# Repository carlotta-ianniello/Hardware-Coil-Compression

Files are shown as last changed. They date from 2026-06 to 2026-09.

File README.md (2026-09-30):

# Hardware Coil Compression

This repository includes the PCB design for a 4x4 mixing matrix that can be used to perform MRI hardware compression at 7T. 

<p align="center">
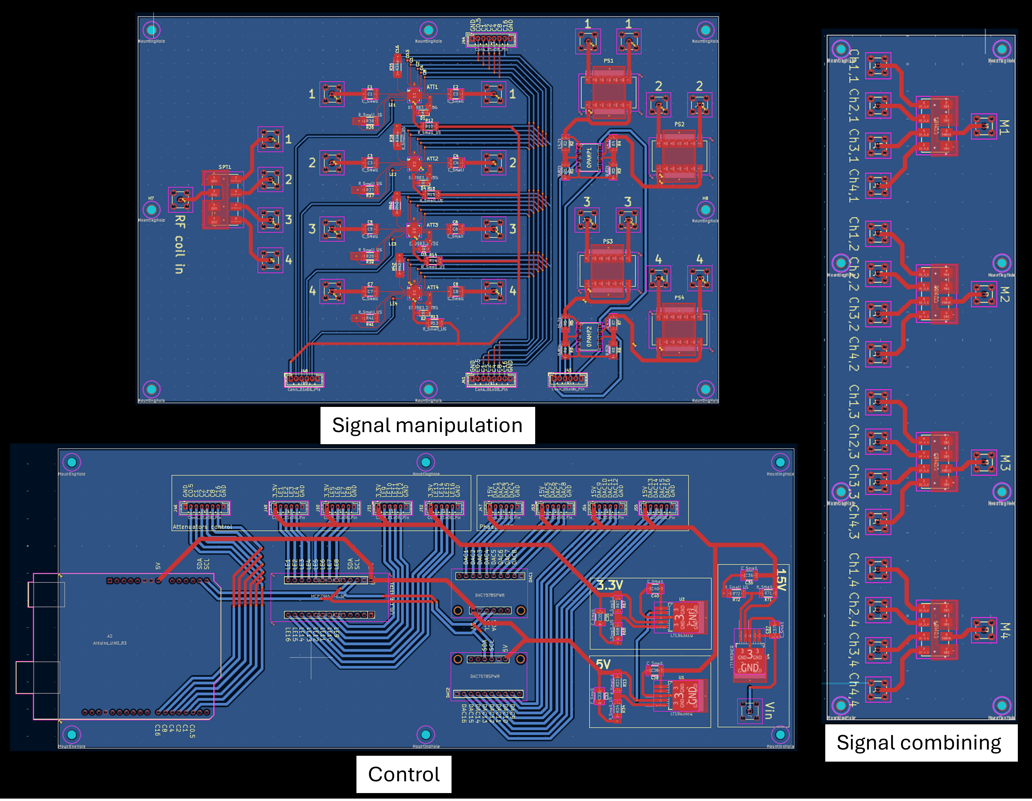
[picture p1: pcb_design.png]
  
</p>

# PCA Compression
The MATLAB script pca_compression_pipeline_ROI.mat calculates the PCA-based weights for coil compression. 

* Load signal and noise data
* Compute noise covariance Psi (for pre-whitening)
* If n_coils=8: evaluate all candidate 4-channel subsets and select the one whose compression matrix phases best fit the hardware phase range, with priority on modes 1 & 2
* Build ROI mask (SNR threshold, radial crop, or both)
* Compute pre-whitened PCA via SVD
* Optimise per-mode global phase rotation into hardware range
* Compute SNR retention maps for 4/3/2/1 virtual modes
* Save compression matrix A for calculate_settings_complex.m

When an ROI is selected or loaded, PCA is only performed in the ROI.

# Settings calculation
The MATLAB script calculate_settings_complex.mat generates optimized hardware settings for a 4×4 RF compression matrix using measured calibration data. It supports loading a target compression matrix, generating random test matrices, or manually defining custom amplitude and phase targets.

The script:

* Loads and normalizes calibration measurements for attenuation and phase
* Interpolates calibration data to a uniform resolution
* Matches target amplitude/phase values to the closest hardware configuration
* Computes attenuator settings, phase shifter voltages, and binary control values for each channel
* Exports the resulting configuration as a `.h` header file for direct integration into the Arduino IDE

This tool is designed for automated calibration and control of modular 4×4 RF matrix hardware systems.

# IDE code
The code to run the compression matrix is included in IDE/4x4_matrix_settings. 

The user will have to insert the correct I2C addresses for DACX578 and MCP23X17:

```cpp
// DAC and I/O Port Expander Addresses
#define DAC1_ADDR 0x4C   // First DAC (0-7 channels)
#define DAC2_ADDR 0x4A   // Second DAC (8-14 channels)
#define IOEXP_ADDR 0x20  // I/O Port Expander
```

Furthermore, in setOutputVoltage supply voltage at the input of the Op Amps needs to be defined. The Op Amp gain is set to 3 but this can also be adjusted based on the resistor values one uses.

```cpp
void setOutputVoltage(int row, int col, float voltage) {
  int index = row * ncol + col; // Flatten 2D to 1D index
  const float ampGain = 3;
  float dacOutputVoltage = voltage / ampGain;
  const float Vcc = 4.07;  // Vcc of Op Amp
  uint16_t dacValue = (uint16_t)round((dacOutputVoltage / Vcc) * 4095);
 ...
```

An example of settings is included in setting1.h.

# Bill of Materials
The complete bill of materials for this project can be found in BOM.xlsx, comprehensive of links to vendors and cost. 

# Reference 
If you use this work, please cite it as follows:

```bibtex
@inproceedings{Ianniello2026,
  author    = {Ianniello, C. and Brown, R.},
  title     = {A flexible hardware-based fully programmable mode-mixing matrix for channel compression applications},
  booktitle = {2026 ISMRM \& ISMRT Annual Meeting \& Exhibition},
  address   = {Cape Town, South Africa},
  year      = {2026}
}
```

C. Ianniello and R. Brown, "A flexible hardware-based fully programmable mode-mixing matrix for channel compression applications," in 2026 ISMRM & ISMRT Annual Meeting & Exhibition, Cape Town, South Africa, 2026.

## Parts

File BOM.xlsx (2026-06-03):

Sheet: first draft
Part number | Description | Vendor | Quantity | Unit Price | Total Price = | Link
DAT-31R5A-PP+ | Step attenuator | Mini-Circuits | 6 | $6.11 | $36.66 | https://www.minicircuits.com/WebStore/dashboard.html?model=DAT-31R5A-PP%2B
JSPHS-42+ | Phase Shifter | Mini-Circuits | 6 | $44.21 | $265.26 | https://www.minicircuits.com/WebStore/dashboard.html?model=JSPHS-42%2B
SCP-4-1W+ | 4 ways splitter | Mini-Circuits | 4 | $34.09 | $136.36 | https://www.minicircuits.com/WebStore/dashboard.html?model=SCP-4-1W%2B
LM358NNS/NOPB-ND | IC OPAMP GP 2 CIRCUIT 8DIP | DigiKey | 10 | $0.55 | $5.50 | https://www.digikey.com/en/products/detail/texas-instruments/LM358N-NOPB/6264?gad_source=1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
AE9986-ND | CONN IC DIP SOCKET 8POS TIN | DigiKey | 10 | $0.13 | $1.34 | https://www.digikey.com/en/products/detail/assmann-wsw-components/A-08-LC-TT/821740
1124-1424-ND | CONN NIMCAMAC RCPT STR 50OHM PCB | DigiKey | 4 | $21.97 | $87.88 | https://www.digikey.com/en/products/detail/lemo/EPB-00-250-NTN/3597321
SAM8944-ND | CONN MCX JACK STR 50 OHM PCB | DigiKey | 30 | $2.82 | $84.46 | https://www.digikey.com/en/products/detail/samtec-inc/MCX-J-P-H-ST-TH1/2685236
LT1963AEQ#TRPBFCT-ND | IC REG LIN POS ADJ 1.5A DDPAK-5 | DigiKey | 4 | $8.79 | $35.16 | https://www.digikey.com/en/products/detail/analog-devices-inc/LT1963AEQ-PBF/807749?gad_source=1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
CRCW201010K0FKEF | RES SMD 10K OHM 1% 3/4W 2010 | DigiKey | 50 | $0.12 | $5.85 | https://www.digikey.com/en/products/detail/vishay-dale/CRCW201010K0FKEF/1174057
CRCW201015K0FKEF | RES SMD 15K OHM 1% 3/4W 2010 | DigiKey | 50 | $0.12 | $5.85 | https://www.digikey.com/en/products/detail/vishay-dale/CRCW201015K0FKEF/1198590
VJ0603Y102JXAAC | CAP CER 1000PF 50V X7R 0603 | DigiKey | 50 | $0.21 | $10.55 | https://www.digikey.com/en/products/detail/vishay-vitramon/VJ0603Y102JXAAC/8305189
315-NC191-ND | SMOOTH FLOW TACK FLUX NO-CLEAN I | DigiKey | 1 | $9.95 | $9.95 | https://www.digikey.com/en/products/detail/chip-quik-inc/NC191/11480391
4902P-25G | LEAD FREE LOW TEMPERATURE SOLDER | DigiKey | 1 | $34.67 | $34.67 | https://www.digikey.com/en/products/detail/mg-chemicals/4902P-25G/7496977
 |  |  |  | TOTAL | $719.49

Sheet: modular board
Part number | Description | Vendor | Qty | Unit Price | Total Price | Link
Arduino UNO R3 | Arduino microcontroler | Arduino | 1 | $27.60 | $27.60 | https://store-usa.arduino.cc/products/arduino-uno-rev3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
DAT-31R5A-PP+ | Step attenuator | Mini-Circuits | 16 | $6.35 | $101.60 | https://www.minicircuits.com/WebStore/dashboard.html?model=DAT-31R5A-PP%2B
JSPHS-42+ | Phase Shifter | Mini-Circuits | 16 | $44.21 | $707.36 | https://www.minicircuits.com/WebStore/dashboard.html?model=JSPHS-42%2B
SCP-4-1W+ | 4 ways splitter/combiner | Mini-Circuits | 8 | $34.09 | $272.72 | https://www.minicircuits.com/WebStore/dashboard.html?model=SCP-4-1W%2B
MCP23017 | 16-port GPIO | Adafruit | 1 | $5.95 | $5.95 | https://www.adafruit.com/product/5346
DAC7578 | 8-port DAC 12-bit | Adafruit | 2 | $24.95 | $49.90 | https://www.adafruit.com/product/6223
LM358NNS/NOPB-ND | IC OPAMP GP 2 CIRCUIT 8DIP | DigiKey | 8 | $0.55 | $4.40 | https://www.digikey.com/en/products/detail/texas-instruments/LM358N-NOPB/6264?gad_source=1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
AE9986-ND | CONN IC DIP SOCKET 8POS TIN | DigiKey | 8 | $0.13 | $1.07 | https://www.digikey.com/en/products/detail/assmann-wsw-components/A-08-LC-TT/821740
1124-1424-ND | CONN NIMCAMAC RCPT STR 50OHM PCB | DigiKey | 4 | $21.97 | $87.88 | https://www.digikey.com/en/products/detail/lemo/EPB-00-250-NTN/3597321
SAM8944-ND | CONN MCX JACK STR 50 OHM PCB | DigiKey | 81 | $2.82 | $228.03 | https://www.digikey.com/en/products/detail/samtec-inc/MCX-J-P-H-ST-TH1/2685236
SAM10607-ND | CONN MCX JACK R/A 50 OHM PCB | DigiKey | 20 | $6.95 | $139.00 | https://www.digikey.com/en/products/detail/samtec-inc/MCX-J-P-H-RA-TH1/1832454?gclsrc=aw.ds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
LT1963AEQ#TRPBFCT-ND | IC REG LIN POS ADJ 1.5A DDPAK-5 | DigiKey | 3 | $8.79 | $26.37 | https://www.digikey.com/en/products/detail/analog-devices-inc/LT1963AEQ-PBF/807749?gad_source=1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
CRCW201010K0FKEF | RES SMD 10K OHM 1% 3/4W 2010 | DigiKey | 16 | $0.12 | $1.87 | https://www.digikey.com/en/products/detail/vishay-dale/CRCW201010K0FKEF/1174057
CRCW201015K0FKEF | RES SMD 15K OHM 1% 3/4W 2010 | DigiKey | 16 | $0.12 | $1.87 | https://www.digikey.com/en/products/detail/vishay-dale/CRCW201015K0FKEF/1198590
CRCW2010100RFKEF | RES SMD 100 OHM 1% 3/4W 2010 | DigiKey | 16 | $0.23 | $3.68 | https://www.digikey.com/en/products/detail/vishay-dale/CRCW2010100RFKEF/1173959
CRCW20102K61FKEF | RES SMD 2.61K OHM 1% 3/4W 2010 | DigiKey | 1 | $0.24 | $0.24 | https://www.digikey.com/en/products/detail/vishay-dale/CRCW20102K61FKEF/1174028
CRCW20101K47FKEF | RES SMD 1.47K OHM 1% 3/4W 2010 | DigiKey | 1 | $0.24 | $0.24 | https://www.digikey.com/en/products/detail/vishay-dale/CRCW20101K47FKEF/1174016
CRCW201011K8FKTF | RES SMD 11.8K OHM 1% 3/4W 2010 | DigiKey | 1 | $0.04 | $0.04 | https://www.digikey.com/en/products/detail/vishay-dale/CRCW201011K8FKEF/1198584
VJ0603Y102JXAAC | CAP CER 1000PF 50V X7R 0603 | DigiKey | 8 | $0.21 | $1.69 | https://www.digikey.com/en/products/detail/vishay-vitramon/VJ0603Y102JXAAC/8305189
445-3925-1-ND | CAP CER 10UF 25V X5R 1812 | DigiKey | 6 | $1.12 | $6.72 | https://www.digikey.com/en/products/detail/tdk-corporation/C4532X5R1E106K250KA/1923414
VTVS3V3ASMF-M3-08 | TVS DIODE 3.3VWM 8.9VC DO219AB | DigiKey | 16 | $0.39 | $6.24 | https://www.digikey.com/en/products/detail/vishay-general-semiconductor-diodes-division/VTVS3V3ASMF-M3-08/10260188
B8B-PH-K-S | CONN HEADER VERT 8POS 2MM | DigiKey | 9 | $0.35 | $3.15 | https://www.digikey.com/en/products/detail/jst-sales-america-inc/B8B-PH-K-S/926617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..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
PHR-8 | CONN RCPT HSG 8POS 2.00MM | DigiKey | 9 | $0.11 | $0.99 | https://www.digikey.com/en/products/detail/jst-sales-america-inc/PHR-8/608630
B6B-PH-K-S | CONN HEADER VERT 6POS 2MM | DigiKey | 16 | $0.27 | $4.32 | https://www.digikey.com/en/products/detail/jst-sales-america-inc/B6B-PH-K-S/926615
PHR-6 | CONN RCPT HSG 6POS 2.00MM | DigiKey | 16 | $0.10 | $1.60 | https://www.digikey.com/en/products/detail/jst-sales-america-inc/PHR-6/608604
LT1963AEQ | Linear Voltage Regulator IC Positive Adjustable 1 Output 1.5A DDPAK-5 | DigiKey | 3 | $8.44 | $25.32 | https://www.digikey.com/en/products/detail/analog-devices-inc/LT1963AEQ-PBF/807749
ASPHSPH24K203 | LEAD SKT-SKT 24AWG BLK 8" TIN | DigiKey | 40 | $0.41 | $16.40 | https://www.digikey.com/en/products/detail/jst-sales-america-inc/ASPHSPH24K203/9918855
900-0732305341-ND | COAX CBL MCX TO MCX 12" | DigiKey | 16 | $10.72 | $171.52 | https://www.digikey.com/en/products/detail/molex/0732305341/15291705
900-0732305323-ND | COAX CABLE MCX TO MCX 6" | DigiKey | 32 | $9.71 | $310.72 | https://www.digikey.com/en/products/detail/molex/0732305323/15291725
1124-1304-ND | COAX ADAPT BNC TO NIM-CAMAC | DigiKey | 4 | $29.03 | $116.12 | https://www.digikey.com/en/products/detail/lemo/ABF-00-250-NTA/3597367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
ABF.00.250.NTA | COAX ADAPT BNC TO NIM-CAMAC | DigiKey | 4 | $30.22 | $120.88 | https://www.digikey.com/en/products/detail/lemo/ABF-00-250-NTA/3597367
 |  |  |  | TOTAL | $2417.90

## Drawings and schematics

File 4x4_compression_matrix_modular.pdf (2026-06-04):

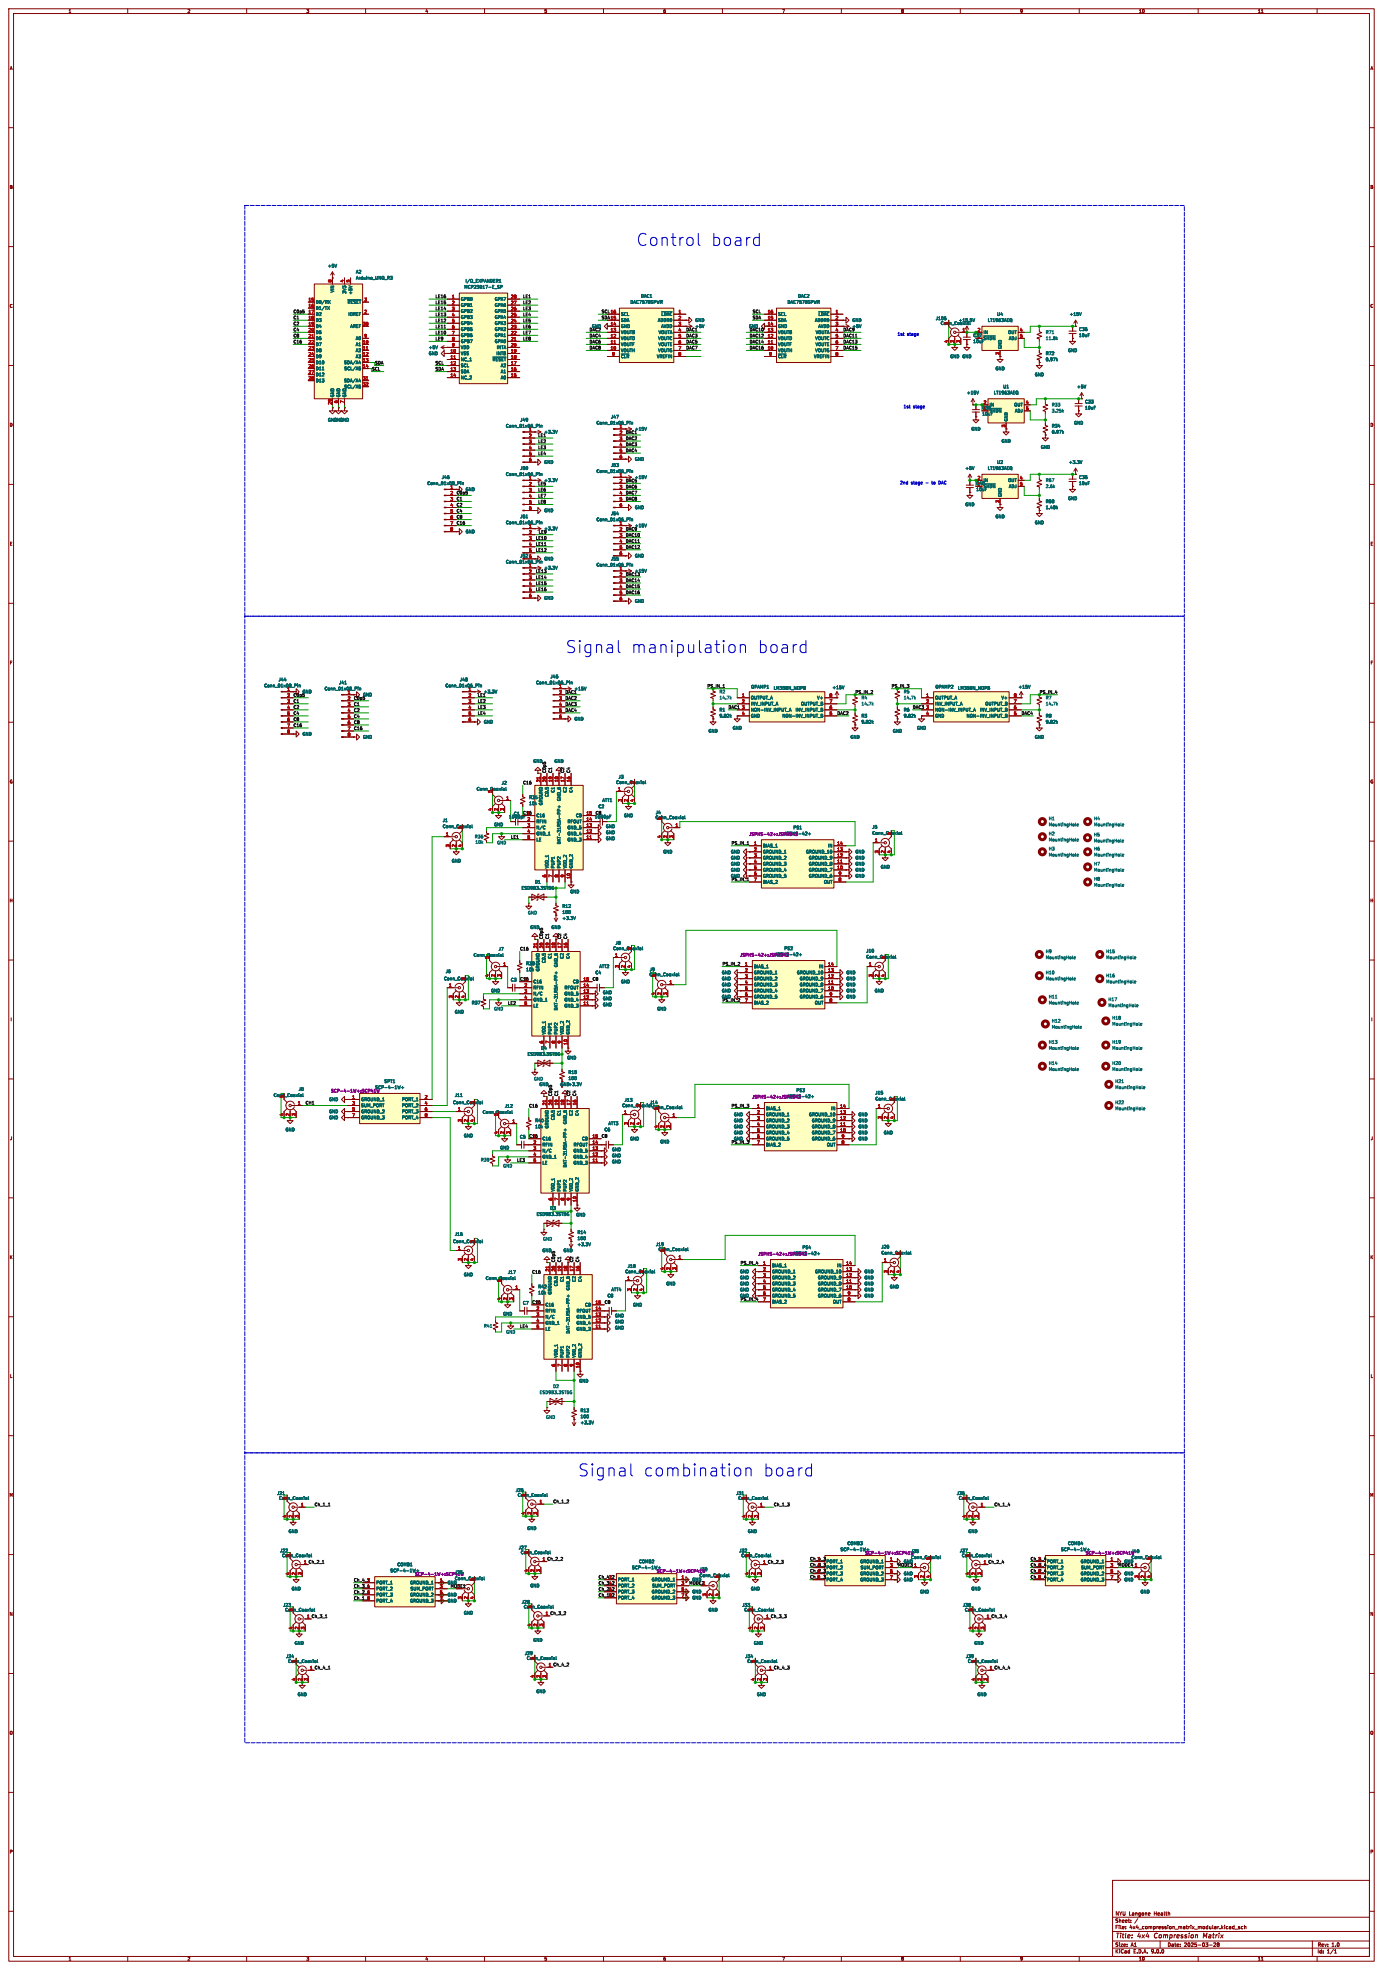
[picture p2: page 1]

IOREF 2 AREF 30 A0 9 A1 10 A2 11 A3 12 SDA/A4 13 SCL/A5 14 SDA/A4 31 SCL/A5 32 A2Arduino_UNO_R3

8 SCL 16 SDA 15 GND 14 VOUTB 13 VOUTD 12 VOUTF 11 VOUTH 10 ~{CLR} 9 +15V

9 C4 16 GND_2 10 C8 15 RFOUT 14 GND_5 13 GND_4 12 GND_3 11 ATT3 DAT-31R5A-PP+ GND GND GND GND

5 4 GND GND GND GND GND GND GND

8 GND GND GND GND

5 4 GND GND GND GND GND GND GND GND

5 4 GNDGND GND GND GND GND GND GND GND GND

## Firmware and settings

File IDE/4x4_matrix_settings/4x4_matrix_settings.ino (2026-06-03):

// Include all Adafruit packages
#include <Adafruit_DACX578.h>
#include <Adafruit_MCP23X17.h>

#include "setting1.h"


Adafruit_DACX578 dac1(12);  // Assuming 12-bit resolution
Adafruit_DACX578 dac2(12);  // Assuming 12-bit resolution
Adafruit_MCP23X17 mcp;

// DAC and I/O Port Expander Addresses
#define DAC1_ADDR 0x4C   // First DAC (0-7 channels)
#define DAC2_ADDR 0x4A   // Second DAC (8-14 channels)
#define IOEXP_ADDR 0x20  // I/O Port Expander

const int nrow = 4;
const int ncol = 4;

// Define Pins
const int attPins[] = { 2, 3, 4, 5, 6, 7 };  // 6-bit Attenuator Control Pins
const int LE_PINS[nrow][ncol] = {
  // LE pins for each attenuator
  { 7,  6,  5,  4},     //{A0, A1, A2, A3}    {ch1,1, ch1,2, ch1,3, ch1,4}
  { 3,  2,  1,  0},     //{A4, A5, A6, A7}    {ch2,1, ch2,2, ch2,3, ch2,4}
  {15, 14, 13, 12},     //{B7, B6, B5, B4}    {ch3,1, ch3,2, ch3,3, ch3,4}
  {11, 10,  9,  8}      //{B3, B2, B1, B0}    {ch4,1, ch4,2, ch4,3, ch4,4}
};


void setOutputVoltage(int row, int col, float voltage) {
  int index = row * ncol + col; // Flatten 2D to 1D index
  const float ampGain = 3;
  float dacOutputVoltage = voltage / ampGain;
  const float Vcc = 4.07;  // Vcc of Op Amp
  uint16_t dacValue = (uint16_t)round((dacOutputVoltage / Vcc) * 4095);

  if (index < 8) {
    dac1.writeAndUpdateChannelValue(index, dacValue);
  } else {
    dac2.writeAndUpdateChannelValue(index - 8, dacValue);
  }

  Serial.print("Set (row=");
  Serial.print(row);
  Serial.print(", col=");
  Serial.print(col);
  Serial.print(") → ");
  Serial.print(voltage);
  Serial.println(" V");
}

// Function to set Attenuation values
void setAttenuation(int row, int col, float attenuation_dB) {

  if (attenuation_dB < 0.0) attenuation_dB = 0.0;
  if (attenuation_dB > 31.5) attenuation_dB = 31.5;

  int value = round(attenuation_dB * 2);

  Serial.print("Attenuator [");
  Serial.print(row);
  Serial.print("][");
  Serial.print(col);
  Serial.print("] → ");
  Serial.print(attenuation_dB);
  Serial.println(" dB");

  Serial.print("Binary: ");
  for (int i = 5; i >= 0; i--) {
    int bitValue = (value >> i) & 1;
    digitalWrite(attPins[i], bitValue);
    Serial.print(bitValue);
  }
  Serial.println();

  mcp.begin_I2C(0x20);

  mcp.digitalWrite(LE_PINS[row][col], HIGH);
  Serial.print("LE pin at I/O output: ");
  for (uint8_t i = 0; i < nrow * ncol; i++) {
    int val = mcp.digitalRead(i);
    Serial.print(val);
    Serial.print(" ");
  }
  delay(1);
  mcp.digitalWrite(LE_PINS[row][col], LOW);

  Serial.println();
}

void setup() {

  Serial.begin(9600);
  Wire.setClock(10000); 

  // Initialize  DAC
  if (!dac1.begin(DAC1_ADDR)) {
    Serial.println("Failed to initialize DAC!");
    while (1)
      ;
  }
  if (!dac2.begin(DAC2_ADDR)) {
    Serial.println("Failed to initialize DAC!");
    while (1)
      ;
  }
  // Initialize I/O Expander
  if (!mcp.begin_I2C(IOEXP_ADDR)) {
    Serial.println("Failed to initialize I/O Port Expander!");
    while (1)
      ;
  }

  // Set pins mode
  for (int i = 0; i < 6; i++) {
    pinMode(attPins[i], OUTPUT);
  }

  for (int r = 0; r < nrow; r++) {
    for (int c = 0; c < nrow; c++) {
      mcp.begin_I2C(0x20);
      mcp.pinMode(LE_PINS[r][c], OUTPUT);
      mcp.digitalWrite(LE_PINS[r][c], LOW);
      Serial.println("LE pins set.");
    }
  }

    // Load setting matrixes from file
  Serial.println(B[0][0]);  // Attenuator settings
  Serial.println(D[0][0]);  // Phase shifter settings
}

void loop() {

  for (int r = 0; r < nrow; r++) {
    for (int c = 0; c < nrow; c++) {
      
      setAttenuation(r, c, B[r][c]);
      setOutputVoltage(r, c, D[r][c]);
      
    }
  }

delay(1000);

}
